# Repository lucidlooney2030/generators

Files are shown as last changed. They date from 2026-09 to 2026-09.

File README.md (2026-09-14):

# Generators

Printable desktop **magnetic generators** by [Austin Carolino](https://github.com/lucidlooney2030).

Educational Faraday machines: mechanical work in → electricity out. **Not** free-energy / overunity devices.

**System / voice-to-parametric process:** [idea-to-print-pipeline](https://github.com/lucidlooney2030/idea-to-print-pipeline)
This repo is the **hardware library** (OpenSCAD + STL + physics notes). New topology work still lands here. Pipeline work (agents, CadQuery port, gates) lands in the system repo.

| Project | Topology | Print first |
|---|---|---|
| [**HF-RF16-SERP**](HF-RF16-SERP/) | Radial-flux **outer rotor**, 16P/16S single-phase **wave** winding | [`stl/HF-RF16-ONEPLATE.stl`](HF-RF16-SERP/stl/HF-RF16-ONEPLATE.stl) |
| [**AFPM-Desk-v1**](AFPM-Desk-v1/) | Axial-flux, hand-crank, single rotor | `stl/` parts |
| [**AFPM-Desk-v2**](AFPM-Desk-v2/) | Axial-flux dual-rotor SSDR + steel back-iron | `stl/fit_coupon.stl` then parts |
| [**Coax-Faraday-v3**](Coax-Faraday-v3/) | Coaxial dual magnet drums + fixed coil | `stl/fit_coupon.stl` then parts |
| [**AFPM-Desk-v4 PoleShoe**](AFPM-Desk-v4-PoleShoe/) | Axial-flux dual-rotor + steel back-iron + pole shoes, 12+12 / 9-coil 3-phase | `stl/fit_coupon.stl` then parts |

## Printer

Anycubic **Kobra 3 Max** (or similar). Prefer **PETG / ABS / ASA / nylon**. HF-RF16: do **not** use PLA.

## Safety

Neodymium magnets pinch and shatter. Eye protection. Dual-magnet and outer-rotor builds have strong attractive forces — assemble with spacers.

## License

MIT — print, remix, share. Attribution appreciated.

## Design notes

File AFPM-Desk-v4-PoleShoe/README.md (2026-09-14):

# Generator Experiments v4 — AFPM-Desk-v4 PoleShoe

**Owner:** Austin Carolino  
**Build name:** AFPM-Desk-v4 PoleShoe  
**Purpose:** Desktop educational **SSDR dual-rotor axial-flux PM** generator with **mild-steel back-iron** plus **mild-steel pole shoes / flux concentrators** under each magnet.  
**Not a free-energy / overunity device.** Electrical energy out ≤ mechanical energy in (hand crank). Orthodoxy: Faraday induction + energy conservation only.

**Date package:** 2026-09-13 (America/New_York)  
**Evolves from:** v2 AFPM-Desk dual-rotor sandwich (`/workspace/generator-experiments/v2/`)

---

## What changed vs v2

| Feature | v2 | v4 (this package) |
|---|----|---|
| Topology | SSDR sandwich + steel back-iron | SSDR + **back-iron + pole shoes** |
| Magnets | 8+8 Ø20×**3** N42 | **12+12** Ø20×**5** N42 (Austin stock) |
| Flux teaching | Back-iron return path | Back-iron **+** Ø18×2 mm shoes under each magnet (reluctance / concentration) |
| Coils | 6 | **9** (true 3-phase Y or Δ) |
| Air gap | ~2 mm/side | **1.5–2.0 mm**/side (parametric spacers) |
| Material | PLA/PETG | **PETG** preferred (Kobra 3 Max) |
| Poles | P=8 → f=4·RPM/60 | **P=12 → f=6·RPM/60** |

---

## Package contents

| Path | Description |
|---|---|
| `README.md` | This overview |
| `BUILD.md` | Assembly steps + safety |
| `PARTS.md` | Labeled part list + debrief |
| `SCHEMATIC.md` | Polarity, wiring, mechanical stack |
| `PHYSICS.md` | Faraday estimates, citations, Voc OOM |
| `PRINT_NOTES.md` | Orientation, supports, PETG settings |
| `FIT_COUPON.md` | Print-first clearance coupon |
| `MANIFEST.md` | File inventory |
| `scad/*.scad` | Parametric OpenSCAD |
| `stl/*.stl` | Binary STLs |
| `sim/` | Numpy Voc vs RPM sanity check |

---

## Topology (why 12/9)

Classic low-speed AFPM educational choice (Latoufis et al. rural AFPM lineage):

1. **12 poles / 9 coils** → natural 3-phase with 120° electrical spacing of coil groups.
2. Thicker Ø20×5 magnets raise source MMF vs v2’s Ø20×3.
3. **Pole shoes** (mild steel, slightly smaller than magnet face) teach flux concentration and reluctance — shoes sit under each magnet, ahead of the full back-iron disc.
4. Coreless plastic stator keeps cogging hand-crankable (still strong dual-N42 attraction — **pinch hazard**).

---

## Quick start

1. Print **`stl/fit_coupon.stl` first** → measure → tweak `scad/parameters.scad` → re-export if needed.
2. Read **PHYSICS.md** + **PARTS.md** (neo pinch / eyes / steel tools).
3. Print remaining STLs (**PETG**, 0.2 mm layers, 5 perimeters / 40% infill / 100% around pockets).
4. Buy BOM: 24× N42 Ø20×5, 24× mild-steel Ø18×2 pole shoes, 2× mild-steel Ø118×1.5 back-iron discs, 28 AWG, 2× 608ZZ, Ø8 shaft ~250 mm.
5. Assemble per **BUILD.md**; set **~1.5–2.0 mm** air gap each side with spacer rings.
6. Measure Voc @ 60–180 RPM; compare to PHYSICS / `sim/`.

---

## Desk-scale electrical targets (order of magnitude)

- Hand crank **60–120 RPM** → roughly **~1–8 Vrms** open-circuit depending on series / Y wiring (see PHYSICS.md).
- @ **120 RPM** conservative model: ~**0.8–1.2 Vrms / coil**, ~**2.5–4 Vrms / phase** (3 coils series), LED-scale after Schottky bridge.
- Educational power: **order of watts**, not utility / battery-bank without further engineering.

---

## Physics stance (explicit)

Converts **mechanical → electrical**. Friction, I²R, eddy/hysteresis in steel, and magnetic drag ⇒ η < 1.  
**No perpetual motion, free energy, or overunity claims.** Pole shoes and thicker magnets improve **coupling** of the work you put in.

---

## Printer assumptions

Anycubic **Kobra 3 Max**, **0.4 mm nozzle**, **0.2 mm layers**, **PETG**.  
Skill: `/home/box/agent-data/workflows/kobra-stl-from-description/SKILL.md`.

Local root: `/workspace/generator-experiments/v4/`

---
*Generator Experiments · Magneat-o cycle · v4 PoleShoe*

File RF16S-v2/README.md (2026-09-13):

# RF16S-v2 — dual-rotor radial flux (CURRENT)

**This is newer than everything else in this repo from 2026-09-13.**

Do not print AFPM-Desk-v1, AFPM-Desk-v2, HF-RF16, or HF-RF88 for this build. Those are earlier machines. This folder is the water-turbine radial generator:

- 16 × Ø20×5 mm discs on the **outer** cup, facing in
- 48 × Ø5×5 mm N52 cylinders on the **inner** hub (16 poles × 3 stacked), facing out
- 16-window coil cage between them
- Matched 16/16 poles, 22.5° pitch, 1.00 mm air gap both sides

## Print these four STLs

| File | What it is |
|---|---|
| `stl/HF-RF16S-v2-OUTER.stl` | Outer cup |
| `stl/HF-RF16S-v2-INNER.stl` | Inner hub (rim + spokes, not a solid puck) |
| `stl/HF-RF16S-v2-CAGE.stl` | Coil cage |
| `stl/HF-RF16S-v2-CAP.stl` | End cap |

Direct downloads (once the STLs are in this folder):
- https://github.com/lucidlooney2030/generators/raw/main/RF16S-v2/stl/HF-RF16S-v2-OUTER.stl
- https://github.com/lucidlooney2030/generators/raw/main/RF16S-v2/stl/HF-RF16S-v2-INNER.stl
- https://github.com/lucidlooney2030/generators/raw/main/RF16S-v2/stl/HF-RF16S-v2-CAGE.stl
- https://github.com/lucidlooney2030/generators/raw/main/RF16S-v2/stl/HF-RF16S-v2-CAP.stl

## Anycubic / Orca

- PETG. Not PLA.
- **Supports = Off**
- Slicer brim = Off (a 0.6 mm brim is already on the part)
- Layer 0.20 mm, first layer 0.24 mm
- 4 walls, 20% gyroid
- Outer walls first
- First layer 20 mm/s, bed ~75 °C, nozzle ~240 °C
- Pockets and cage windows face **up**
- Peel the brim when cold

## Magnets

Outer: N-S-N-S around the circle.
Inner: each column of 3 small magnets is one pole, all three the same way, **opposite** the outer magnet it faces (they attract across a window).

Steel strip 1.5 × 20 mm behind **both** rings.

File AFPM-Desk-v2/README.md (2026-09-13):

# Generator Experiments v2 — AFPM-Desk Dual-Rotor Sandwich

**Owner:** Austin Carolino  
**Build name:** AFPM-Desk-v2  
**Purpose:** Desktop educational **dual-rotor axial-flux permanent-magnet (AFPM)** generator with **steel back-iron**.  
**Not a free-energy / overunity device.** Electrical energy out ≤ mechanical energy in (hand crank). Orthodoxy: Maxwell–Faraday induction + energy conservation only.

**Date package:** 2026-09-10 (America/New_York)  
**Evolves from:** v1 AFPM-Desk (single rotor, 8× N42, 6 coils) — Drive folder [v1](https://drive.google.com/drive/folders/12ztOcHBTHuGbHydsOmjWQckuVxojFjWz)

---

## What changed vs v1

| Feature | v1 | v2 (this package) |
|---|----|---|
| Topology | Single rotor / single stator | **SSDR sandwich**: dual rotors + stator between |
| Magnets | 8× N42 Ø20×3 | **8+8** (16×) N42 Ø20×3 facing across stator |
| Back-iron | None (plastic return) | **Mild steel discs** Ø100×1.5 mm behind each magnet set |
| Coils | 6 | **6** (continuity; 3-phase capable) |
| Expected B_g | ~0.25–0.40 T | ~**0.40–0.60 T** (order-of-magnitude) |
| Air gap | 2–3 mm one side | **1.5–2.5 mm each side** magnet↔coil |
| Learning goal | Basic Faraday demo | Higher flux, feel stronger cogging, compare single vs dual |

---

## Package contents

| Path | Description |
|---|---|
| `README.md` | This overview |
| `BUILD.md` | Assembly steps + print notes |
| `PARTS.md` | Labeled part list, BOM, physics debrief per part |
| `SCHEMATIC.md` | Polarity, wiring, mechanical stack |
| `PHYSICS.md` | Faraday estimates, citations, sanity checks |
| `FIT_COUPON.md` | Print-first clearance coupon procedure |
| `PRINT_NOTES.md` | Orientation, supports, pause-for-magnets |
| `scad/*.scad` | Parametric OpenSCAD sources |
| `stl/*.stl` | Binary STLs for Anycubic Kobra 3 Max |

---

## Topology choice (documented)

**8+8 magnets / 6 coils** kept deliberately:

1. **Continuity with v1** — reuse coil winding skill and 8-magnet pattern; buy 8 more discs.
2. **Educational clarity** — alternating N/S on each rotor; facing magnets **attract** (N faces S across gap) so flux threads the coils axially.
3. **3-phase option** — wire coils as A=(C0+C3), B=(C1+C4), C=(C2+C5) like v1.
4. **Why not 12/9 yet?** Commercial DIY AFPM often uses 12 poles / 9 coils for smoother 3-phase at wind-turbine scale (Latoufis et al.). For desk hand-crank learning, 8/6 is adequate and simpler. A v3 could migrate to 12+12/9 if wanted.

**Steel back-iron role:** provides a low-reluctance return path between adjacent poles on each rotor, raising air-gap flux density versus the plastic-only v1 disc, and reducing stray flux behind the magnets (Gieras / AFPM literature; Latoufis rural-electrification AFPM notes).

**Coreless stator:** plastic plate + copper coils only — **no iron teeth** → low cogging for hand crank (still some detent from magnet–magnet attraction across the gap). Tradeoff: thicker magnetic gap than slotted iron stator → B_g lower than industrial iron-cored AFPM, but safer and smoother for learning.

---

## Quick start

1. Print **`fit_coupon.stl` first** → measure → tweak `scad/parameters.scad` if needed → re-export.
2. Read **PHYSICS.md** + **PARTS.md** (safety: neo pinch / eyes).
3. Print remaining STLs (PLA or PETG, 0.2 mm layers, ≥3–4 perimeters on rotors/frame).
4. Buy BOM (16× N42, 2× steel discs, 28 AWG, 608 bearings, Ø8 shaft ~220 mm).
5. Assemble per **BUILD.md**; set **~2 mm air gap each side**.
6. Measure open-circuit AC @ ~60–120 RPM; compare to PHYSICS estimates.

---

## Desk-scale electrical targets (order of magnitude)

- Hand crank **60–120 RPM** → roughly **~1–8 Vrms** open-circuit depending on series/3-phase wiring (see PHYSICS.md).
- Peak educational power: **order of watts** (LED / small loads), **not** mains / battery-bank charging without further engineering.
- Voltage stays **low-energy educational** at hand speed — still use eye protection for magnets.

---

## Physics stance (explicit)

Converts **mechanical → electrical**. Friction, I²R, and magnetic drag ⇒ η < 1. **No perpetual motion, free energy, or overunity claims.** Dual rotors and steel raise coupling; they do not create energy.

---

## Printer assumptions

Anycubic **Kobra 3 Max**, **0.4 mm nozzle**, **0.2 mm layers**, **PLA or PETG**. Skill: `/home/box/agent-data/workflows/kobra-stl-from-description/SKILL.md`.

---

## Upload note

Large binary STLs often cannot upload intact via the Google Drive connector. Docs (markdown) upload fine; place STLs in Drive **Generator Experiments / v2** manually from this package if needed.

Local root: `/workspace/generator-experiments/v2/`

---
*Generator Experiments · Magneat-o cycle · v2*

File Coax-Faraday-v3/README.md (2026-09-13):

# Generator Experiments v3 — Coaxial Faraday Desk Generator

**Austin Carolino** · educational Faraday machine · orthodox physics only  
**Not** free energy / overunity / perpetual motion.

## What it is
A **simple three-layer coaxial** hand-crank generator for Anycubic **Kobra 3 Max** (PETG, 0.4 mm nozzle, 0.2 mm layers):

1. **Outer** magnet drum — Ø20×5 mm N42 discs, faces **inward**
2. **Middle** fixed copper coil stator (bobbin)
3. **Inner** magnet drum — Ø20×5 mm N42 discs, faces **outward**

**Topology:** outer + inner drums are **mechanically locked** and rotate together as one rotor; the coil cylinder is the **stationary stator**. No brushes. Flux crosses the coil **radially**.

## Why this topology
- Stationary coils → no brushes, desk-safe low voltage
- Dual facing magnets raise gap flux vs single-sided
- Matched pole count (P=8) with alternating N/S around the circumference

## Magnet decision
**Assumption:** “20×5 mm” = **Ø20×5 mm discs** (not bar stock) — common catalog size (e.g. supermagnete S-20-05-N N42).

**Inner choice: Ø20×5 discs (not Ø3×5 cans).**  
Simulation FoM \(P\cdot\Phi\): Ø20 dual ≫ Ø3 dual (area ratio \((3/20)^2\approx2.25\%\)). Outer Ø20 already limits pole count, so tiny inner magnets buy no useful frequency and lose flux.

## Expected order of magnitude (@ 120 RPM, baseline)
From `sim/` (N42, P=8, 2 mm gaps, 26 AWG, dual Ø20):

| Quantity | Estimate |
|---|---|
| \(f\) | 8 Hz |
| Voc rms | **~4 V** |
| Voc peak | **~6 V** |
| LED current (100 Ω + 2 V LED, naive bridge) | **~17 mA** |

Hand-crank 60–300 RPM → LED demo territory; not a power plant.

## Package layout
```
v3/
  README.md  PHYSICS.md  DEBRIEF.md  SCHEMATIC.md  PRINT_NOTES.md
  scad/   parametric OpenSCAD
  stl/    binary STLs
  sim/    numpy sweep + CSV + plots
  scripts/export_stls.sh
```

## Quick start
1. Print `fit_coupon.stl` in PETG; dial magnet/bearing fits.
2. Print drums, stator halves, base, hubs, crank.
3. Epoxy magnets with **polarity_jig** (alternating).
4. Wind stator (26–28 AWG), assemble, crank into an LED + series resistor.

See **DEBRIEF.md** for BOM/assembly and **PHYSICS.md** for equations & safety.

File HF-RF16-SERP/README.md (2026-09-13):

# HF-RF16-SERP  16P/16S

**Radial-flux OUTER-ROTOR generator · single-phase wave (serpentine) winding**  
For **Austin Carolino** · units **mm** · FROM SCRATCH (not axial flux, no pancake coils, no 9-bobbin concentrated winding, no magnet platter).

| | |
|---|---|
| Topology | Rotor cup spins **around** stationary stator drum |
| Poles / slots | **16** disc magnets / **16** axial grooves |
| Winding | One continuous serpentine/wave, 26 AWG, target 80–120 turns |
| Air gap | **1.00 mm** (locked; do not exceed 1.2) |

---

## Geometry conflict resolution

**Problem.** Early notes mixed a drum bore of 47.00 with groove floor **r = 47.38**, leaving only **0.38 mm** of printed wall (below the ≥2.00 mm minimum). Sleeve outer was corrected to **r = 55.38** (wall 0.80), and a copper fill of “~7.2” no longer matched.

**Chosen resolution (preferred):**

| Stack item | Value |
|---|---|
| Magnet inner-face pitch radius | **56.38** |
| Air gap | **1.00** |
| Sleeve OUTER / INNER r | **55.38** / **54.58** (wall 0.80) |
| Printed bore **radius** | **47.00** → bore **Ø94.00** |
| Groove floor r | **49.00** (not 47.38) |
| Printed wall (bore → floor) | **2.00** |
| Copper radial fill | 55.38 − 0.80 − 49.00 = **5.58** (revises “7.2”) |
| Groove open (pre-sleeve) | r = **55.38** |
| Land / groove arcs @ 55.38 | **9.75** / **12.00** (sum 21.75 = pitch arc; **no ±0.5 tweak**) |

**Steel tube:** Legacy BOM “OD~47” matched the **bore radius** figure. Corrected bought tube: **OD ≈ 94 mm**, wall ~3 mm, length ~28 mm — slip fit in Ø94 bore.

Angular pitch remains **16 × 22.50°**.

---

## Key dimensions

| Parameter | mm |
|---|---|
| Magnets | 16× Ø20.00×5.00 NdFeB, faces inward, N-S-N-S |
| Magnet backs | r = 61.38 |
| Rotor OD | 132.00 |
| Back-iron groove | r = 61.38–62.88 × axial 20.20; strip cut **386** |
| Stator axial (groove+galleries) | 32.00 |
| Pocket Ø / depth / lip ID | 20.30 / 5.20 / 18.40 (lip thk 0.80) |
| 608ZZ seats | Ø22.20 × 7.20 deep (×2: rotor + cap) |

---

## Deliverables

| File | Description |
|---|---|
| `hf_rf16_params.py` | Locked parameters (`MAG_COUNT=16`) |
| `hf_rf16_cad.py` | Parametric CadQuery → STEP + STL |
| `hf_rf16_drawing.py` | Drawing generator |
| `HF-RF16-ROTOR.stl` / `.step` | Outer rotor cup |
| `HF-RF16-STATOR.stl` / `.step` | Grooved stator drum |
| `HF-RF16-SLEEVE.stl` / `.step` | Two 180° post-wind shells |
| `HF-RF16-CAP.stl` / `.step` | End cap + 2nd bearing |
| `HF-RF16-ASSEMBLY.step` | Positioned assembly |
| `HF-RF16-ONEPLATE.stl` | All parts, 8 mm gaps (300 mm bed) |
| `HF-RF16-DRAWING.pdf` (+ png/svg) | Dimensioned drawing set |
| `PHYSICS_NOTE.md` | Faraday sanity |
| `PRINT_NOTES.md` | Print orientation & settings |
| `BOM.md` | Bought + printed BOM |

Rebuild:

```bash
cd /workspace/generator-experiments/HF-RF16
.venv/bin/python hf_rf16_cad.py
.venv/bin/python hf_rf16_drawing.py
```

---

## Build overview

Print rotor (pockets up), stator (grooves up), sleeve halves (flat), and cap (flat) in PETG/ABS/ASA/nylon — never PLA. Press 16× Ø20×5 NdFeB into rotor pockets alternating N-S (centrifugal seats outboard; lip retains inward). Slide 1.5×20 mild-steel strip (cut 386) into the back-iron groove. Fit steel tube Ø94 into stator bore. Wave-wind 26 AWG through all 16 grooves with end-turn galleries (up 1, over, down 2, …), use the return slot for multi-turn, exit tails through cap grommets. Clip on sleeve halves after winding. Assemble on Ø8 shaft with two 608ZZ (rotor cup rotates; stator fixed via cap). Rectify with a 4-diode bridge and ≥1000 µF.

**Constraints honored:** radial flux only · magnets on inner wall of rotating cup · coil active length axial · serpentine pitch = pole pitch · no stator teeth · air gap 1.00.

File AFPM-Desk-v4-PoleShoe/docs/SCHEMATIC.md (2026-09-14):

# SCHEMATIC — AFPM-Desk-v4 PoleShoe

## 1. Mechanical stack (axial, along shaft)

```
[crank][608ZZ][hub][rotorA+shoes+magnets][steel A]
        |← ~1.5–2.0 mm air →|
      [stator + 9 coils]
        |← ~1.5–2.0 mm air →|
[steel B][rotorB+shoes+magnets][hub][608ZZ]
```

Nominal air gap each side: magnet face ↔ coil/bobbin face. Tune with `spacer_1mm` / `1p5mm` / `2mm`.

---

## 2. Rotor polarity (P=12)

Looking along shaft toward rotor A stator face. Stations every 30°.

| Station index | Angle | Rotor A face (→ stator) | Rotor B face (→ stator) |
|---|---|---|---|
| 0 | 0° | **N** | **S** |
| 1 | 30° | **S** | **N** |
| 2 | 60° | **N** | **S** |
| … | … | alternate | opposite of A |

Facing pair at each station: **N faces S** so axial flux threads the coils. Adjacent magnets on one rotor alternate → circumferential return via back-iron.

Pole shoe under every magnet (both rotors).

Printed etch: bar = N, cross = S (rotor A pattern on jig; rotor B opposite).

---

## 3. Coil map (9 coils)

Coils seated at angles \(20° + i·40°\) (i = 0…8) so pockets sit between/aligned for 12-pole AFPM coupling.

**3-phase grouping (120° electrical):**

| Phase | Coil indices | Mechanical spacing |
|---|---|---|
| **A** | 0, 3, 6 | every 3rd coil |
| **B** | 1, 4, 7 | |
| **C** | 2, 5, 8 | |

Within a phase, series-connect with **aiding** sense (same wind direction relative to flux). If Voc collapses, reverse one coil in the group.

### Star (Y)

```
Phase A ────●
Phase B ────●─── neutral (optional bring-out)
Phase C ────●
```

Line-line Voc ≈ √3 × phase Voc (balanced OC idealization).

### Delta (Δ)

```
A ──●── B
 \     /
  ●───●
    C
```

Higher current capability, lower line V — useful for low-V LED experiments.

---

## 4. LED demo (desk-safe)

```
[Y or Δ phases] → Schottky bridge → C filter (optional 100–470 µF) → Rseries (100–220 Ω) → LED
```

Si bridge (~1.4 V drop) eats much of the LED budget; **Schottky** preferred.

---

## 5. Frequency check

\[
f = \frac{\mathrm{RPM}}{60}\cdot\frac{P}{2} = 6\cdot\frac{\mathrm{RPM}}{60}
\]

| RPM | f (Hz) |
|-----|---|
| 60 | 6 |
| 120 | 12 |
| 180 | 18 |

Scope one coil: period should match. Wrong f → wrong pole count / mechanical slip (should be locked).

---

## 6. What not to wire

- Do **not** connect to mains.
- Do **not** short all coils while spinning at high RPM (heating + strong drag).
- Do **not** claim self-running / overunity — Lenz drag always costs mechanical power.

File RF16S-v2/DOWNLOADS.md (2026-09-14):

# Downloads

STLs are not in git yet. Rebuild from the pipeline family, or attach the local meshes named:

- radial_flux_16_inward_rotor.stl
- 03_serpentine_coil_former(1).stl
- 02_inner_magnet_hub.stl

System repo: https://github.com/lucidlooney2030/idea-to-print-pipeline/tree/main/families/radial_outer

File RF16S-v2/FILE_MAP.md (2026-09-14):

# Name map (your files → this folder)

| Your filename | This project |
|---|---|
| `radial_flux_16_inward_rotor.stl` | outer cup → `stl/HF-RF16S-v2-OUTER.stl` |
| `03_serpentine_coil_former(1).stl` | coil cage → `stl/HF-RF16S-v2-CAGE.stl` |
| `02_inner_magnet_hub.stl` | inner hub → `stl/HF-RF16S-v2-INNER.stl` |

Parametric source of truth for the rebuild:  
https://github.com/lucidlooney2030/idea-to-print-pipeline/tree/main/families/radial_outer

Those three exact names were not in this repo when checked. If you still have the meshes, put them in `RF16S-v2/reference/` so we can compare bbox vs the CadQuery rebuild. Do not hand-edit them.

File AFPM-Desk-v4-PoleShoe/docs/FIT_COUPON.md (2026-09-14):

# FIT_COUPON — print first

File: `stl/fit_coupon.stl` (95×55×8 mm)

## What it tests

1. **Shaft hole ladder** — Ø8.2, 8.3, 8.4, 8.5 (pick slip fit for Ø8 shaft).
2. **608ZZ seats** — OD −0.20 / −0.15 / −0.10 mm (pick firm press).
3. **Magnet pocket** — Ø20.25 × depth ~5.15 for Ø20×5 disc.
4. **Pole-shoe pocket** — Ø18.30 × depth ~2.15 for Ø18×2 steel.
5. **M3 clear (3.4) / tap pilot (2.5)**.

## Procedure

1. Print in **PETG**, same settings as final parts.
2. Calipers: record actual hole IDs and pocket depths.
3. Edit `scad/parameters.scad`:
   - `clearance_slip`, `press_interference`
   - `magnet_pocket_xy`, `magnet_pocket_z`
   - `pole_shoe_pocket_xy`, `pole_shoe_pocket_z`
4. Re-export affected STLs with OpenSCAD before printing rotors/frame.

Do **not** skip this — dual neo arrays punish bad fits.

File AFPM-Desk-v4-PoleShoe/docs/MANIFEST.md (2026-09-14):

# MANIFEST — AFPM-Desk-v4 PoleShoe

Package root: `/workspace/generator-experiments/v4/`  
Archive: `/workspace/afpm_desk_v4_full_package.tar.gz`

## Documentation

- README.md
- BUILD.md
- PARTS.md
- SCHEMATIC.md
- PHYSICS.md
- PRINT_NOTES.md
- FIT_COUPON.md
- MANIFEST.md (this file)

## OpenSCAD (`scad/`)

- parameters.scad
- rotor_disc.scad, rotor_disc_A.scad, rotor_disc_B.scad
- stator_plate.scad, coil_bobbin.scad
- base_frame.scad, shaft_hub.scad, bearing_cap.scad
- hand_crank.scad, crank_handle.scad
- spacer_ring.scad, spacer_1mm.scad, spacer_1p5mm.scad, spacer_2mm.scad
- fit_coupon.scad, polarity_jig.scad, pole_shoe_holder.scad
- electronics_tray.scad

## Binary STLs (`stl/`)

- base_frame.stl
- rotor_disc_A.stl, rotor_disc_B.stl
- stator_plate.stl, coil_bobbin.stl
- shaft_hub.stl, bearing_cap.stl
- hand_crank.stl, crank_handle.stl
- spacer_1mm.stl, spacer_1p5mm.stl, spacer_2mm.stl
- fit_coupon.stl, polarity_jig.stl, pole_shoe_holder.stl
- electronics_tray.stl

## Simulation (`sim/`)

- afpm_desk_v4.py
- sweep_results.csv
- sim_summary.txt
- voc_vs_rpm.png, voc_vs_gap.png

## Regenerating STLs

```bash
cd /workspace/generator-experiments/v4
for p in scad/*.scad; do
  b=$(basename "$p" .scad)
  case "$b" in parameters|rotor_disc|spacer_ring) continue;; esac
  openscad -o "stl/${b}.stl" "$p"
done
# then convert ASCII→binary if needed via trimesh / stl2bin
```

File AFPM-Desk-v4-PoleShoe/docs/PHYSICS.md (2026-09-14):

# PHYSICS — AFPM-Desk-v4 PoleShoe

Educational estimates. **Reject perpetual motion / overunity / “magnets alone make free power.”**  
Mechanical work against Lenz drag → electrical energy (+ heat).

Assumptions stated. **No fabricated lab measurements** — order-of-magnitude from standard EM relations + cited material properties. Validate with a DMM/tach on your build.

---

## 1. Governing equations

\[
\mathcal{E} = -N\frac{d\Phi_B}{dt}
\]

For approximately sinusoidal flux through one coil:

\[
\Phi(t)\approx\Phi_{\mathrm{peak}}\sin(2\pi f t)
\quad\Rightarrow\quad
\mathcal{E}_{\mathrm{peak}}\approx N\cdot 2\pi f\cdot\Phi_{\mathrm{peak}}
\]

\[
\mathcal{E}_{\mathrm{rms}}\approx\mathcal{E}_{\mathrm{peak}}/\sqrt{2}
\]

Electrical frequency for \(P\) poles:

\[
f=\frac{\mathrm{RPM}}{60}\cdot\frac{P}{2}
\]

**v4:** \(P=12\) → \(f=6\times(\mathrm{RPM}/60)\).

| RPM | \(f\) (Hz) |
|-----|---|
| 60  | 6 |
| 90  | 9 |
| 120 | **12** |
| 180 | 18 |

(Refs: synchronous-machine frequency relation; AFPM modelling e.g. Gieras; [MDPI Energies 13(21):5741](https://www.mdpi.com/1996-1073/13/21/5741).)

---

## 2. Magnet material

**Assumption:** Ø20×5 mm axial N42 discs (Austin stock).

| Grade | Br (typical) | Sources |
|---|---|---|
| **N42** | **1.28–1.32 T** (use **1.30 T**) | [supermagnete S-20-05-N](https://www.supermagnete.nl/eng/data_sheet_S-20-05-N.pdf); manufacturer N42 bands |

Gap flux **≠ Br**. Remanence is a material property; useful \(B_g\) depends on reluctance of air + coil path + leakage + steel return.

---

## 3. Topology & flux path

```
[steel back-iron A][pole shoe][magnet A Ø20×5]
        -- air gap (~1.75 mm) --
              [coil / plastic]
        -- air gap (~1.75 mm) --
[magnet B Ø20×5][pole shoe][steel back-iron B]
```

- Facing magnets **N↔S** across stator → axial flux through coils.
- Adjacent magnets on one rotor **alternate** N/S.
- **Back-iron:** low-reluctance circumferential return (classic SSDR AFPM).
- **Pole shoes (Ø18×2 mild steel under each magnet):** locally lower reluctance and teach **flux concentration / reluctance** — shoes do not create energy; they reshape the magnetic circuit.

Coreless stator (no iron teeth): smoother hand crank, thicker effective magnetic gap than slotted industrial AFPM.

---

## 4. Air-gap flux density model (assumptions)

Non-steel path (order of magnitude):

| Segment | Thickness |
|---|---|
| Magnet A | 5 mm |
| Mechanical air A | ~1.5–2.0 mm (use 1.75) |
| Coil / plastic stator | ~10 mm effective |
| Mechanical air B | ~1.75 mm |
| Magnet B | 5 mm |

Crude series-reluctance estimate (µ_gap ~ 1):

\[
B_g \approx B_r\cdot\frac{L_{m,\mathrm{eff}}}{L_{m,\mathrm{eff}}+g_{\mathrm{eff}}}\cdot k_{\mathrm{leak}}
\]

with \(L_{m,\mathrm{eff}}\approx 2\times 5\,\mathrm{mm}\), \(g_{\mathrm{eff}}\approx 2\cdot\mathrm{gap}+\mathrm{coil\_axial}\), and \(k_{\mathrm{leak}}\approx 0.65\) (dual + steel + shoes; conservative).

| Case | \(B_g\) (model) |
|---|---|
| v2-like (3 mm mags, steel, no shoes) | ~0.23 T (same formula) |
| v4 no shoes (5 mm + steel) | ~0.32 T |
| **v4 + pole shoes (baseline)** | **~0.36 T** |
| Upper teaching band (less leakage) | ~0.45–0.55 T |

**Central conservative estimate used below: \(B_g = 0.36\,\mathrm{T}\).**  
Upper band ~0.50 T if shoes + steel couple better than the crude leak factor — treat as a sensitivity case, not a measured value.

Magnet face area:

\[
A_m=\pi(0.010)^2=3.14\times10^{-4}\,\mathrm{m}^2
\]

Coupling coil vs magnet footprint \(k_c\approx 0.70\) (9 coils / 12 poles fractional alignment):

\[
\Phi_{\mathrm{peak}}\approx k_c B_g A_m
\approx 0.70\times 0.36\times 3.14\times10^{-4}
\approx 7.9\times10^{-5}\,\mathrm{Wb}
\]

(Upper band Φ ≈ \(1.1\times10^{-4}\) Wb at \(B_g=0.50\,\mathrm{T}\).)

**vs v2:** thicker magnets + higher pole count + shoes raise \(f\) and improve Φ relative to a like-for-like reluctance model; absolute Voc also depends on turns and wiring.

---

## 5. Turns & resistance (LED demo recommendation)

| Item | Recommendation |
|---|---|
| Wire | **28 AWG** enamel Cu (~0.32 mm bare; ~0.213 Ω/m @ 20 °C typical) |
| Turns / coil | **~200** hand-wind target (bobbin window allows more if filled carefully) |
| Mean turn length | ≈ 0.08 m (24×16 mm core rectangle) |
| \(R_{\mathrm{coil}}\) | ≈ **3.4 Ω** @ 200 turns |

Alt: **26 AWG**, ~150 turns → lower R, easier LED current, slightly lower Voc.

---

## 6. Open-circuit voltage estimates

### One coil @ 120 RPM (\(f=12\,\mathrm{Hz}\), \(N=200\), Φ = 7.9×10⁻⁵ Wb)

\[
\mathcal{E}_{\mathrm{peak,1}}\approx 200\cdot 2\pi\cdot 12\cdot 7.9\times10^{-5}\approx 1.19\,\mathrm{V}
\]

\[
\mathcal{E}_{\mathrm{rms,1}}\approx 0.84\,\mathrm{V}
\]

Upper band (\(B_g=0.50\,\mathrm{T}\)): ~**1.1–1.2 Vrms** / coil.

### Scale with RPM (∝ f ∝ RPM)

| RPM | \(f\) | Voc rms / coil (cons.) |
|-----|---|---|
| 60 | 6 | ~0.42 V |
| 120 | 12 | ~**0.84 V** |
| 180 | 18 | ~1.3 V |

### Wiring aggregates @ 120 RPM (rough)

| Config | Expectation OC |
|---|---|
| Single coil | ~0.8–1.2 Vrms |
| 1 phase = 3 coils series | ~**2.5–3.5 Vrms** |
| Y line-line | ~**4–6 Vrms** (√3 × phase, ideal) |
| All series (careful aiding) | higher, phase-risk if wrong |

**Hand-crank band (60–180 RPM):** plan on **~1–8 Vrms** open-circuit depending on wiring — **LED-scale after rectification**, not utility voltage.

`sim/afpm_desk_v4.py` reproduces these curves (`voc_vs_rpm.png`, `sweep_results.csv`).

Diode bridge drop (~0.6–1.4 V) is significant at LED voltages — use Schottky.

---

## 7. Rough power

Example: rectified ~3 V into LED drawing 20–50 mA → \(P\sim 0.06\)–\(0.15\,\mathrm{W}\).  
Vigorous crank / smaller gap / denser winding → **~0.5–2 W** educational ballpark.

\[
P_{\mathrm{elec}} < P_{\mathrm{mech}}=\tau\omega
\]

Copper \(I^2R\), bearing friction, windage, and eddy/hysteresis in back-iron + pole shoes all reduce η. At hand RPM, steel eddy is modest if discs are thin (1.5–2 mm).

---

## 8. What pole shoes do *not* do

- Do **not** create energy from magnets alone.
- Do **not** enable self-running / overunity.
- Do **not** violate Faraday or Kelvin–Planck.
- They reshape reluctance so **more of your crank work** couples into \(d\Phi/dt\) (and a bit more steel loss).

---

## 9. Safety (magnetic)

- Dual **12+12 N42 Ø20×5** arrays: **severe pinch/crush**. Assemble with spacers; never put fingers in the gap.
- Non-magnetic tools; keep steel tools away from open faces.
- NdFeB shatter risk — eye protection; epoxy fully.
- Desk-safe low V electrically; still avoid hard shorts while cranking.

---

## 10. Citations & further reading

1. Faraday’s law — Griffiths *Introduction to Electrodynamics*; any intro EM text.
2. [Modeling of Axial Flux Permanent Magnet Generators](https://www.mdpi.com/1996-1073/13/21/5741) — Energies 13(21):5741 (2020).
3. Latoufis et al. — DIY AFPM sizing for small wind (12-pole / 9-coil practice).
4. Habib et al., SSDR coreless AFPM — *Alexandria Engineering Journal* (2024).
5. N42 NdFeB \(B_r\) — manufacturer datasheets (e.g. supermagnete S-20-05-N).
6. Reluctance / permeance methods — standard machine design texts (Gieras *Axial Flux Permanent Magnet Brushless Machines*).

Nuance: published AFPM papers often target kW machines; **scaling laws apply**, but absolute V/I here are desk-learning.

---

## 11. Measurement plan

1. Tach / phone RPM on rotor mark.
2. DMM ACV one coil vs RPM → slope ∝ \(N\Phi\).
3. Scope frequency → confirm \(f=6\cdot\mathrm{RPM}/60\).
4. Vary gap with spacer rings → Voc falls as gap rises.
5. Optional: compare Voc with vs without pole shoes (same magnets/gap) — expect modest rise with shoes if leakage was significant.

---
*End PHYSICS — AFPM-Desk-v4 PoleShoe*

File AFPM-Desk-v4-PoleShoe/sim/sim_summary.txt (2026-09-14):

AFPM-Desk-v4 PoleShoe sim summary
================================
Assumptions: N42 Br=1.3 T, P=12, gap=1.75 mm/side, coil axial=10 mm
Bg with pole shoes+back-iron (conservative): 0.360 T
Bg without shoes (steel only): 0.321 T
Bg v2-like (3 mm mag, no shoes): 0.232 T
Bg upper teaching band (shoes): 0.485 T
Phi_peak (conservative): 7.907e-05 Wb
Turns/coil (28 AWG hand target): 200, R≈3.4 Ω

@ 120 RPM: f=12.0 Hz
  Voc 1 coil rms (cons.): 0.843 V
  Voc 1 coil rms (upper): 1.138 V
  Voc phase (3 ser):      2.529 V
  Voc Y line-line:        4.381 V

Order-of-magnitude @ 120 RPM: ~0.8–3 Vrms / coil; ~2–8 Vrms / phase; LED-scale after rectification.
NOT free energy — mechanical work against Lenz drag supplies the power.

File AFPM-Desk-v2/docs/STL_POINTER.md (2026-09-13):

# STL / OpenSCAD package note — AFPM-Desk-v2

Large binary STL files often cannot upload intact through the Google Drive connector.

**Local package on Magneat-o computer:**
- Docs + STLs: `/workspace/generator-experiments/v2/`
- Archive: `/workspace/afpm_desk_v2_stls.tar.gz` (~1.8 MB of stl+scad+scripts)

**Please drop these into this Drive folder (`Generator Experiments / v2`) from the chat archive or Magneat-o desktop:**
- All files under `stl/*.stl` (17 binary STLs)
- Optionally `scad/*.scad` and `scripts/export_stls.sh`

Docs in this folder (README, BUILD, PARTS, SCHEMATIC, PHYSICS, PRINT_NOTES, FIT_COUPON, MANIFEST, DEBRIEF) are already uploaded as text.

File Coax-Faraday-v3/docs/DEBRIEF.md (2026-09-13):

# DEBRIEF — Coax Faraday v3

## Labeled parts (print)

| STL | Role | Qty |
|-----|---|-----|
| `fit_coupon.stl` | Magnet + 608 fit calibration | 1 |
| `outer_magnet_drum.stl` | Outer rotor cup, Ø20×5 pockets (N-in / S-in alt.) | 1 |
| `inner_magnet_drum.stl` | Inner rotor, Ø20×5 pockets (N-out / S-out alt.) | 1 |
| `stator_bobbin.stl` | Split coil former (both halves in one STL) | 1 file |
| `shaft_hub.stl` | Locks outer closed end + pilots inner to shaft | 1 |
| `rotor_end_cap.stl` | Open-end lock: outer drum ↔ shaft | 1 |
| `base.stl` | Floor + two 608 posts | 1 |
| `bearing_cap.stl` | Bearing retainers | 2 |
| `hand_crank.stl` + `crank_handle.stl` | Drive | 1+1 |
| `polarity_jig.stl` | Alternating N/S seating guide | 1 |
| `spacer_*.stl` | Axial shims 1 / 1.5 / 2 mm | as needed |

**Bought hardware**

| Item | Spec | Qty | ~USD |
|---|---|-----|---|
| NdFeB discs | Ø20×5 mm N42 (Ni) | 16 | 25–40 |
| 608-2RS bearings | 8×22×7 mm | 2 | 3–6 |
| Shaft | Ø8 mm steel rod ~150 mm | 1 | 3–5 |
| Magnet wire | 26 AWG (or 28) enamel Cu ~30–50 m | 1 | 8–12 |
| M3 screws/nuts | assorted 8–20 mm | ~20 | 3–5 |
| Epoxy | 5–min or slow clear | 1 | 5–8 |
| LED + 100 Ω | demo load | 1 set | 1 |
| Bridge rectifier | W04G or 4×1N4007 | 1 | 1–2 |
| **Total** | | | **~50–80 USD** |

Optional: multimeter, hand tach / phone RPM app, thin wood stick for magnet placement.

---

## Assembly (short)

1. **Fit coupon** — confirm magnet press/slip and 608 seat; adjust OpenSCAD `magnet_pocket_xy` / `press_interference` if needed; reprint drums only if off.
2. **Magnets** — using `polarity_jig`, mark alternating poles. Epoxy 8 into **inner** (faces out) and 8 into **outer** (faces in). Match angles so facing pairs are N-in/N-out (see SCHEMATIC). Cure fully.
3. **Wind stator** — clamp bobbin halves; wind 26 AWG into the radial window (aim fill ~50–60%). Bring out leads through exit slot. Tape/varnish. Mount feet to base.
4. **Rotor** — press bearings into base posts; shaft through. Mount `shaft_hub` + outer drum closed end + inner drum on shaft so magnets align axially with coil. Fit `rotor_end_cap`. Verify **~2 mm** radial air gap each side (no rub).
5. **Crank** — attach hand crank; spin free (expect cogging).
6. **Electrical** — coil → bridge → 100 Ω → LED (or Voc on DMM AC/DC as wired).

---

## What to measure

| Test | Method | Expect (order) |
|---|---|---|
| Voc vs RPM | DMM + tach at 60/120/300 RPM | ~2 / ~4 / ~10 Vrms (baseline model) |
| Loaded LED | series 100 Ω | glow by ~100–150 RPM |
| Gap sensitivity | spacer / reprint | Voc falls as gap ↑ |
| Cogging | feel / stall torque | stronger with dual magnets |
| R_coil | DMM | tens of ohms (sim ~50 Ω @ 26 AWG) |

Compare to `sim/voc_vs_rpm.png`. Large misses → check polarity map, turns count, rubs, or gap.

---

## Optimum simple build (picked)

- Dual Ø20×5, P=8, 2 mm gaps, 26 AWG, locked dual-rotor / fixed stator  
- Skip Ø3 cans, skip 3-phase for v3 (single-phase series is enough for LED lab)

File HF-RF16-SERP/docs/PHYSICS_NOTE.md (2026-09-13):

# PHYSICS_NOTE — HF-RF16-SERP 16P/16S

Orthodox Faraday estimate only. No exotic claims.

## Machine class

- **Radial flux**, **outer rotor**: magnets on the **inner** cylindrical wall of a rotating cup.
- Flux crosses the **1.00 mm** air gap **radially** into the stator.
- Coil **active length is axial** (20 mm groove span), not circumferential pancakes.
- **16 poles / 16 slots**, single-phase **serpentine (wave)** winding with pitch = pole pitch = **22.5°**.
- Stator has **open grooves / lands (no ferromagnetic teeth)**; mild-steel tube provides flux return at the bore.

## Why EMF appears

Each magnet pole sweeps past an axial conductor once per pole pitch. For a single axial run of length ℓ in a radial field B_r at radius R, the motional EMF is on the order of:

\[
e \sim B_r\,\ell\,v = B_r\,\ell\,(\omega R)
\]

With N_turns series wave turns (each turn ≈ two axial runs for a full go-and-return across the machine, depending on count), AC EMF scales as:

\[
E_{\mathrm{rms}} \sim k\,N\,B_r\,\ell\,R\,\omega
\]

Electrical frequency: \(f_e = N_p\,n_{\mathrm{rev}}\) with \(N_p = 8\) pole-**pairs** (16 poles) → \(f_e = 8\,n\) (rev/s).

## Order-of-magnitude (sanity, not a promise)

Assume:

| Symbol | Rough value |
|---|---|
| B_r in gap | 0.3–0.6 T (NdFeB Ø20×5 behind ~1 mm gap + sleeve; no iron teeth → toward low end) |
| ℓ active | ~0.020 m |
| R | ~0.056 m |
| N | 80–120 turns |
| ω | 157 rad/s (≈1500 rpm) |

Then per-turn peak ~ BℓωR ≈ 0.4×0.02×157×0.056 ≈ **0.07 V**, ×100 turns × coupling factor ~0.3–0.6 (single-phase serpentine, leakage without teeth) → **low single-digit to low tens of volts** open-circuit at that speed. Power is modest; this is a learning / light-duty PMG, not a multi-kW machine.

Rectify with a full-wave bridge and bulk capacitor (≥1000 µF) for DC experiments.

## Design implications called out

1. **No stator teeth** → higher reluctance / leakage than a slotted iron stator; B_r and coupling are deliberately conservative above.
2. **Steel tube at bore r≈47** is the main flux return; lands are printed polymer.
3. **Outer rotor** keeps magnet mass at larger radius (good for inertia / turbine coupling) with centrifugal seating into pocket floors.
4. Serpentine single-phase → pulsating torque / ripple; expect vibration vs. a three-phase machine.

All estimates are classical Faraday / Lorentz; validate on the bench with a known rpm and scope.

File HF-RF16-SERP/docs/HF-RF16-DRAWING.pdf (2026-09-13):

### Axial cross-section (radial stack-up)

### Rotor polar layout — 16×22.5° magnet pockets

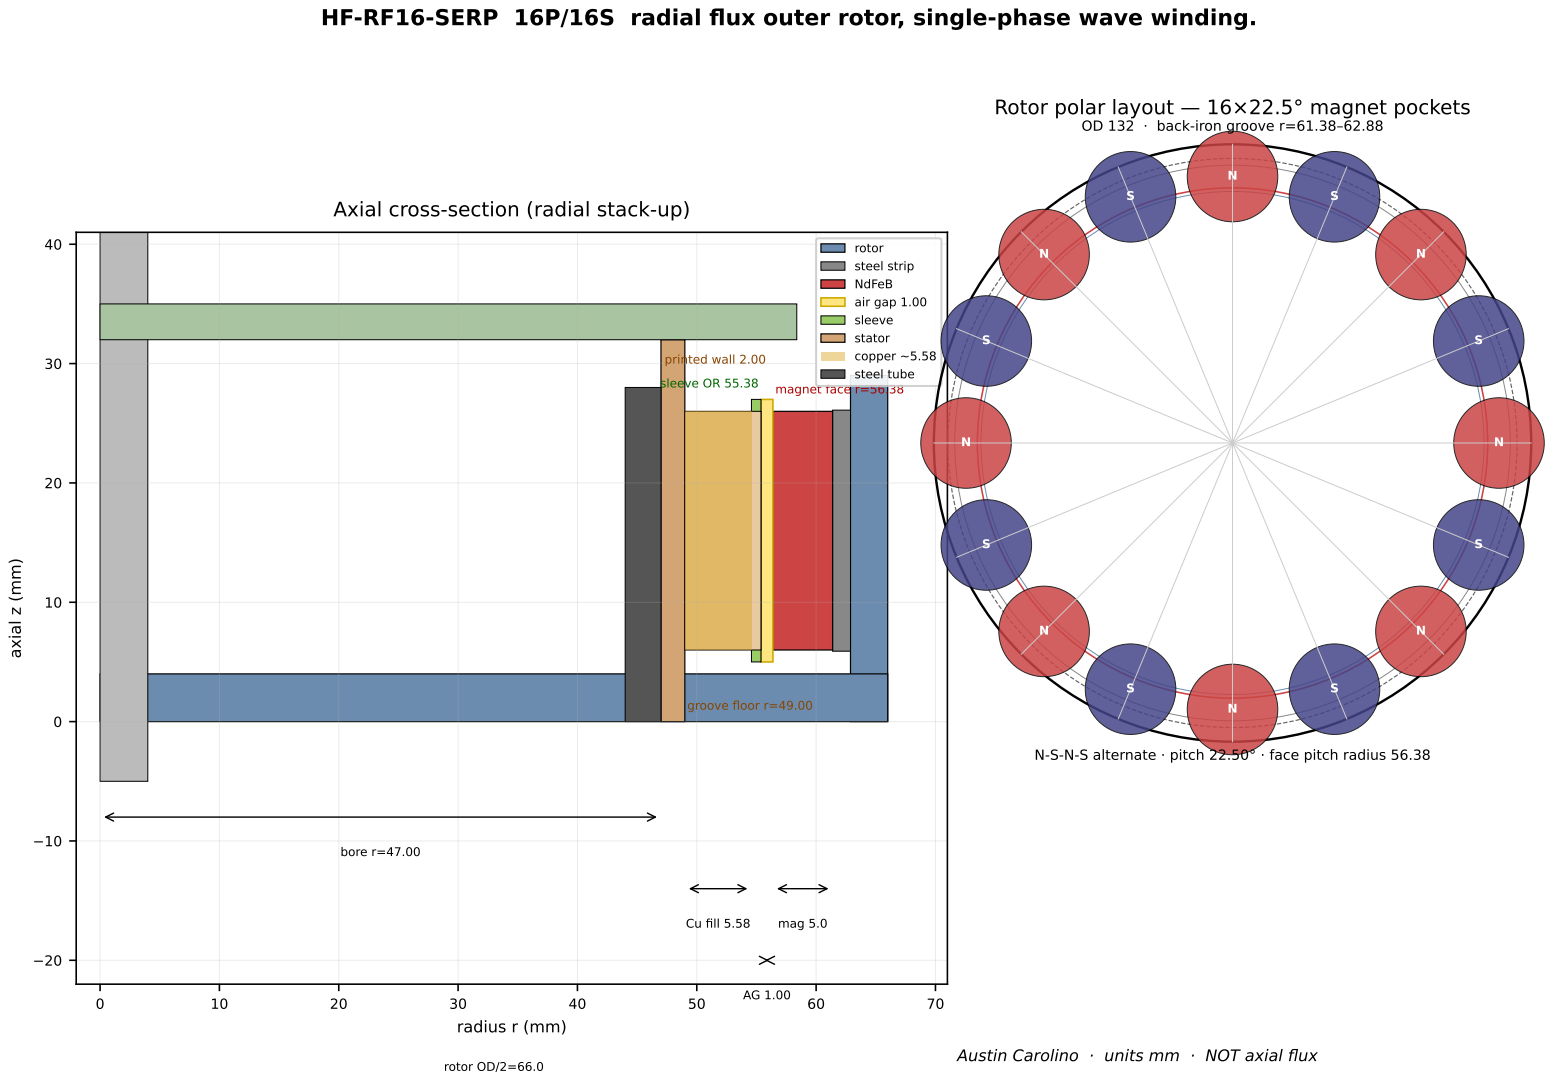
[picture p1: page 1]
radius r (mm); axial z (mm); bore r=47.00; Cu fill 5.58; mag 5.0; rotor OD/2=66.0; groove floor r=49.00

HF-RF16-SERP 16P/16S radial flux outer rotor, single-phase wave winding.

OD 132 · back-iron groove r=61.38–62.88

printed wall 2.00 | | rotor steel strip NdFeB air gap 1.00 sleeve stator copper ~5.58

OR 55.38 magnet face r=56.38 sleeve | steel tube

N-S-N-S alternate · pitch 22.50° · face pitch radius 56.38

Austin Carolino · units mm · NOT axial flux

N | S | N | S | N | S | N | S | N | S | N | S | N | S | N | S

Magnets (rotor) — polarity above axial runs · serpentine pitch = pole pitch = 22.5°

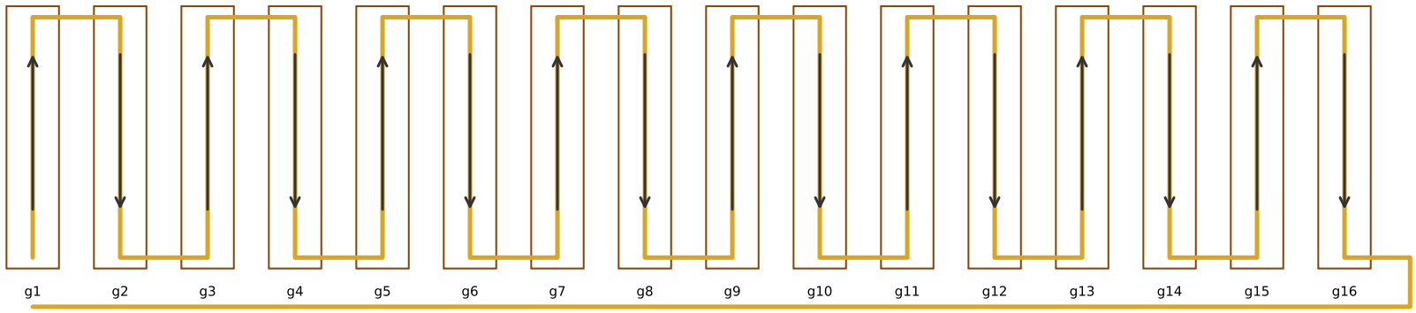
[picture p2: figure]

26 AWG wave winding · target 80–120 turns · tails out cap · bridge + ≥1000 µF

### Unrolled 16-slot square-wave / serpentine winding

Parameter | Value
MAG_COUNT | 16
Pole/slot pitch | 22.50°
Magnet face radius | 56.38
Magnet back radius | 61.38
Air gap | 1.00
Sleeve outer / inner r | 55.38 / 54.58
Bore diameter (radius) | 94.00 (47.00)
Groove floor radius | 49.00
Printed wall bore→floor | 2.00
Copper radial fill | 5.58
Groove / land arc @55.38 | 12.00 / 9.75
Rotor OD | 132.00
Steel strip cut length | 386

### Key dimensions (mm) — resolved geometry

CONFLICT: Original notes had drum bore r=47.00 with groove floor r=47.38, leaving only 0.38 mm printed wall (below the ≥2.00 mm minimum). Copper fill quoted as ~7.2 mm was inconsistent with a corrected sleeve outer r=55.38.

RESOLUTION (preferred):
- Magnet face r = 56.38, air gap = 1.00 exactly (≤1.2).
- Sleeve OUTER r = 55.38, wall = 0.80 → INNER r = 54.58.
- Bore RADIUS = 47.00 (diameter 94.00) for steel flux-return tube OD≈94.
- Groove floor r = 49.00 → printed wall = 2.00 mm.
- Copper radial fill = 55.38 − 0.80 − 49.00 = 5.58 mm (revises “7.2”).
- Groove open at r=55.38 before sleeve; land/groove arcs 9.75 / 12.00 at
that radius sum to pitch arc 21.75 mm (16×22.5°) — no ±0.5 adjustment needed.
- Legacy BOM “steel tube OD~47” referred to the bore RADIUS figure; corrected tube OD≈94 mm wall~3 length~28 to match Ø94 bore.

### Geometry conflict resolution

Qty | Item | Notes
16 | NdFeB Ø20×5 | axially magnetized, N-S alt.
1 | Steel strip 1.50×20.00×386 | mild steel back-iron
1 | Steel tube OD≈94 wall~3 L~28 | flux return (bore Ø94)
2 | 608ZZ bearing | 22×8×7
1 | Shaft Ø8 | through both bearings
— | M3 screws / heat-set inserts | rotor 6×; stator/cap 4×
— | M2 or snaps | sleeve clips
1 spool | 26 AWG magnet wire | serpentine 80–120 turns
4 | Diodes (bridge) | full-wave rectifier
1 | Capacitor ≥1000 µF | DC filter
1 | HF-RF16-ROTOR.stl | PETG/ABS/ASA/nylon
1 | HF-RF16-STATOR.stl | grooves UP
1 | HF-RF16-SLEEVE.stl | 2×180° shells
1 | HF-RF16-CAP.stl | bearing + grommets

### Hardware BOM (bought) + key printed parts

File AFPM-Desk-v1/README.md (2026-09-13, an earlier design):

# Generator Experiments v1 — AFPM-Desk Learning Generator

**Owner:** Austin Carolino
**Purpose:** Desktop educational build for **magnetic electricity production via Faraday induction** (generator / alternator principles).
**Not a free-energy / overunity device.** Output energy comes only from mechanical work you put in (hand crank or small motor). Orthodoxy: Maxwell–Faraday induction only.

## What this is

**AFPM-Desk-v1** is a **hand-crank axial-flux permanent-magnet (AFPM) learning generator**:

- One 3D-printed **rotor disk** carries **8× N42 neodymium discs** in alternating N/S polarity.
- A fixed **stator** holds **6 coils** of magnet wire facing the rotor across a small air gap.
- Turning the crank changes magnetic flux through the coils → induced EMF (AC).
- A bridge rectifier makes low-voltage DC for LEDs / measurement.

Desk-scale targets: measurable volts, LED loads, multimeter experiments — not household power.

## Package contents

| Path | Description |
|---|---|
| `DEBRIEF.md` | Parts, BOM, assembly, physics notes, measurements, failure modes |
| `SCHEMATIC.md` | Wiring, magnet polarity layout, ASCII diagrams |
| `schematics/wiring_polarity.svg` | Vector schematic |
| `stl/*.stl` | All 3D-printable parts |
| `scad/*.scad` | OpenSCAD sources (editable) |
| `README.md` | This overview |

## Printable parts (STL)

- `base_plate.stl` — desk base with bearing posts + stator pillars
- `rotor_disk.stl` — magnet pockets + polarity etch marks
- `stator_mount.stl` — 6 coil pockets + wire channels
- `shaft_hub.stl` — couples 8 mm shaft to rotor
- `hand_crank.stl` / `crank_handle.stl` — drive
- `bearing_cap.stl` — retaining caps (print 2)
- `coil_former.stl` — winding jig
- `electronics_tray.stl` — rectifier / LED bay
- `magnet_polarity_jig.stl` — N/S placement aid
- `spacer_ring.stl` — 1 mm air-gap spacers (print several)

## Quick start

1. Read **DEBRIEF.md** (safety first — neo magnets pinch and shatter).
2. Print STLs (PLA/PETG, 0.2 mm layers, ≥3 perimeters for rotor/base).
3. Buy BOM items (N42 20×3 mm discs, 28 AWG magnet wire, 608 bearings, etc.).
4. Wind 6 coils (~200 turns each), assemble per DEBRIEF, set **~2–3 mm air gap**.
5. Measure open-circuit AC with a multimeter while cranking; then rectifier → LED.

## Expected learning payoff

- Feel **cogging** as magnets pass coils.
- See **AC** frequency scale with RPM; rectified DC lights LEDs.
- Compare measured V vs Faraday estimates in DEBRIEF.
- Vary air gap / RPM / series-parallel coil wiring and watch EMF change.

## Physics stance (explicit)

This converts **mechanical energy → electrical energy**. Friction, copper I²R, and magnetic drag mean electrical out ≪ mechanical in. There is **no** claim of perpetual motion, free energy, or overunity.

## License / reproducibility

Open, reproducible educational design. Modify OpenSCAD parameters in `scad/parameters.scad` and re-render.

---
*Generator Experiments · Cycle 1 · v1*

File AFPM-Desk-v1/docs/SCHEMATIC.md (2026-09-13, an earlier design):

# SCHEMATIC — AFPM-Desk-v1 Wiring & Magnet Polarity

Educational Faraday-induction generator. Low-voltage only. No mains.

---

## 1. Magnet polarity layout (rotor face view)

Looking at the **magnet face** of `rotor_disk` (pockets toward you).  
8 magnets on PCD 70 mm. **Alternate N / S.**

```
                 M1 (N)
                   |
          M8 (S)   |   M2 (S)
             \     |     /
              \    |    /
               \   |   /
        M7 (N) -----●----- M3 (N)
               /   |   \
              /    |    \
             /     |     \
          M6 (S)   |   M4 (S)
                   |
                 M5 (N)
```

- Even indices in OpenSCAD (0,2,4,6) → **N** (bar etch on back of disk).  
- Odd indices (1,3,5,7) → **S** (cross etch).  
- Use `magnet_polarity_jig.stl` during epoxy.

**Rule:** Adjacent magnets must oppose. Same-facing neighbors cancel useful flux change.

---

## 2. Stator coil positions

6 coils, indexed C0…C5, angularly offset +30° from magnet zero so coils sit between pole centers at rest (reduces detent at park; still continuous EMF when spinning).

```
              C0
               |
        C5     |     C1
           \   |   /
            \  |  /
      C4 ---- ● ---- C2
            /  |  \
           /   |   \
        C3     |     
```

**Wind direction:** All coils wound the **same way** on the former (e.g. clockwise when viewing from rotor). Mark start (dot) and finish leads.

---

## 3. Recommended first wiring — series single string → bridge → LED

Simplest for first light:

```
  C0s ── C0f──┐
              ├── C1s ── C1f ──┐
                               ├── … (series all 6) …
                                              └── C5f ──●── AC1
  C0 start = AC2 ●──────────────────────────────────────┘

  AC1 ────┐         ┌──── (+) ─── 220–470Ω ─── LED ─── (−)
          │  BRIDGE │
  AC2 ────┤  RECT   ├──── (−) ─────────────────────────────┘
          └─────────┘
```

ASCII bridge (classic diamond):

```
          AC1
           │
      ┌────┴────┐
      │         │
     D1▷       ◁D2
      │         │
     (+)       (−)
      │         │
     D3▷       ◁D4
      │         │
      └────┬────┘
           │
          AC2
```

Diode orientation: cathodes of D1/D2 toward (+); anodes of D3/D4 toward (−).  
Module packages (W04M) already wire this; ~1.4 V total forward drop — significant at LED voltages, so series-aid coils matter.

---

## 4. Better educational wiring — 3-phase (v1 optional)

Group coils 120° apart:

| Phase | Coils (series) |
|---|---|
| A | C0 + C3 |
| B | C1 + C4 |
| C | C2 + C5 |

Connect phase finishes (or starts — be consistent) in **star (Y)**: join one end of A,B,C; take other ends to a **3-phase bridge** (or 6 discrete diodes).  
Star neutral can float for LED experiments.

Phase EMF ≈ 2× single-coil EMF (series aiding if wound same sense and spaced correctly).

---

## 5. Measurement taps

```
  [Coil string] ──┬── DMM ACV (open circuit)
                  │
                  ├── Bridge ── DMM DCV / LED load
                  │
                  └── Scope CH1 (optional AC waveform)
```

Tachometer on crank or phone RPM app on rotor mark.

---

## 6. Mechanical stack (side view)

```
   CRANK ═╤════ SHAFT ════╤═ HUB ═ ROTOR+MAGNETS
          │               │              ↕ air gap 2–3 mm
       BRG│            BRG│           STATOR+COILS
          │               │              │
        ══╧══ BASE PLATE ═╧══════════════╧══
                         │
                   ELECTRONICS TRAY (rectifier, LED)
```

---

## 7. Polarity check procedure

1. Spin slowly by hand with DMM on ACV across one coil.  
2. Note voltage.  
3. If series pair **decreases** V when connected, reverse one coil’s leads (series opposing → fix to series aiding).

---

## 8. SVG

See also `schematics/wiring_polarity.svg` for a printable diagram.

---
*End SCHEMATIC — AFPM-Desk-v1*

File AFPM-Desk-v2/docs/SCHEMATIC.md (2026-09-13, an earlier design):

# SCHEMATIC — AFPM-Desk-v2 Polarity, Wiring, Stack

Low-voltage educational Faraday generator. No mains.

---

## 1. Mechanical stack (side view, shaft horizontal)

```
  CRANK ══╤════ SHAFT ═══════════════════════════════╤══
          │                                           │
         BRG                                         BRG
          │                                           │
         H1                                           H2
          │                                           │
     STEEL-A                                         STEEL-B
     ROTOR-A  ▓▓▓ N/S magnets facing ──►    ◄── magnets S/N ▓▓▓  ROTOR-B
          │         ↕ air ~2 mm                 ~2 mm ↕        │
          │              ║ STATOR + 6 COILS ║                  │
          │              ║   (coreless)     ║                  │
          └──────────────╨──── pillars ────╨──────────────────┘
                              BASE FRAME
                                 │
                          ELECTRONICS TRAY
```

Flux (aligned pole): `steel-A → mag-A → air → coil → air → mag-B → steel-B` with circumferential return in each back-iron between adjacent poles.

---

## 2. Facing polarity rule

At angular station \(i\):

| Rotor | Facing stator |
|---|---|
| A, even \(i\) | **N** |
| A, odd \(i\) | **S** |
| B, even \(i\) | **S** (opposite of A) |
| B, odd \(i\) | **N** |

```
        Rotor A face (toward stator)          Rotor B face (toward stator)
                 M0 N                                    M0 S
              M7 S   M1 S                             M7 N   M1 N
                 \   /                                   \   /
           M6 N ---●--- M2 N                       M6 S ---●--- M2 S
                 /   \                                   /   \
              M5 S   M3 S                             M5 N   M3 N
                 M4 N                                    M4 S
```

Adjacent on same rotor: always alternate. Across gap: always attract (N↔S).

---

## 3. Coil layout

6 coils C0…C5 at angles \(30° + i\cdot 60°\) (offset from magnet zero).

```
              C0
               |
        C5     |     C1
           \   |   /
      C4 ---- ● ---- C2
           /   |   \
        C3     |
```

Wind all coils the **same sense**. Mark start (•) and finish.

---

## 4. Recommended first wiring — one phase → bridge → LED

Phase A = C0 + C3 in series (180° apart, same polarity sense when aiding):

```
  C0• ── C0f ── C3• ── C3f ──●── AC1
  C0 start tied after verifying aiding ……………●── AC2   (adjust)

  AC1 ──┐         ┌── (+) ── 220–470Ω ── LED ── (−)
        │ BRIDGE  │
  AC2 ──┤ RECT    ├── (−) ────────────────────────┘
        └─────────┘
```

Bridge diamond:

```
        AC1
         │
    ┌────┴────┐
   D1▷       ◁D2
    │         │
   (+)       (−)
    │         │
   D3▷       ◁D4
    └────┬────┘
         │
        AC2
```

---

## 5. Full 3-phase (educational upgrade)

| Phase | Coils series |
|---|---|
| A | C0 + C3 |
| B | C1 + C4 |
| C | C2 + C5 |

Star (Y): join one end of A,B,C; other ends → 3-phase bridge (or 6 diodes).  
Verify each series pair is **aiding** before starring.

---

## 6. Mermaid — energy flow

```mermaid
flowchart LR
  Hand[Hand crank τω] --> Shaft
  Shaft --> Rotors[Dual rotors + Neos + steel]
  Rotors -->|dΦ/dt| Coils[Stator coils]
  Coils -->|AC EMF| Rect[Bridge]
  Rect --> LED[LED load]
  Coils -->|Lenz drag| Rotors
```

---

## 7. Polarity check

1. Spin slowly; DMM ACV on one coil.  
2. Add second coil in series — V should **rise**. If it falls, reverse one lead.  
3. Repeat for each phase pair.

---
*End SCHEMATIC — AFPM-Desk-v2*

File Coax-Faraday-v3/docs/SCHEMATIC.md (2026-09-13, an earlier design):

# SCHEMATIC — Polarity & Wiring (v3)

## Mechanical topology

```
        rotating together (ROTOR)              fixed (STATOR)
   ┌─────────────────────────────┐         ┌──────────────┐
   │ Outer drum  Ø20×5  (N/S)in  │         │              │
   │         ↓ radial flux        │←—gap—→ │  Copper coil │←—gap—→ Inner drum Ø20×5 (N/S)out
   │                              │         │   bobbin     │
   └────────── shaft_hub / end_cap / shaft ─┴──────────────┘
                         608 bearings on base
```

Outer + inner mechanically locked via `shaft_hub` + `rotor_end_cap` on common Ø8 shaft.  
Coil cylinder bolted to base — **no brushes**.

---

## Polarity map (P=8)

View along +shaft. Stations every 45°.

```
        0° OUTER:N-in     INNER:N-out
       /    \
  315° S     N 45°
       |  COIL |
  270° N     S 90°
       \    /
      225°   135°
        180° OUTER:N-in   INNER:N-out
```

**Rule:** at each station, outer face polarity = inner face polarity (both toward coil), then **alternate** around the circle.  
Flux path: outer face → radial through coil → inner face → return via adjacent opposite pole pair.

Use `polarity_jig.stl`: tall peg = N seat, short peg = S seat (or label with marker).

---

## Coil wiring (single-phase — default)

Wind the stator window as **one continuous coil** (or P concentrated sectors **in series**, same sense relative to alternating poles).

```
[Coil start]----+----[Bridge ~]----+----[100 Ω]----[LED+]
                |                  |
[Coil end]------+----[Bridge ~]    +----[LED−]----gnd/return
                     [Bridge +]--------------------┘
                     [Bridge −]---- system return
```

- Bridge: W04M/W04G or 4×1N4007  
- LED: 2 V class; series **100 Ω** (tune 47–220 Ω)  
- For Voc measurement: disconnect LED; measure AC across coil or DC after bridge

**Series sectors (optional):** 8 slots → connect so voltages add at the electrical frequency \(f=\mathrm{RPM}/60\cdot P/2\).

---

## 3-phase (optional, not required)

If you wind 3 groups at 120° electrical (for P=8, 60° mechanical between groups):

```
  A ──┐
  B ──┼── star or delta ──→ 3-ph bridge → DC rail
  C ──┘
```

v3 BOM/sim assume **single-phase** for simplicity.

---

## Desk-safe notes

- Open-circuit volts are low (single-digit to low teens at hand crank)  
- Do **not** connect to mains  
- Shorted coil while cranking → strong drag + heating

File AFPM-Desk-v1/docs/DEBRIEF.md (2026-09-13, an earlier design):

# DEBRIEF — Generator Experiments v1 (AFPM-Desk)

**Build name:** AFPM-Desk-v1  
**Type:** Hand-crank **axial-flux permanent-magnet** educational generator  
**Physics basis:** Faraday’s law of induction (orthodox; not free-energy)  
**Audience:** Austin Carolino — desktop learning build  
**Date package:** 2026-09-07 (America/New_York)

---

## 1. Why this design (selection rationale)

Candidates considered:

| Option | Pros | Cons for desk v1 |
|---|---|---|
| Brushed DC motor as dynamo | Cheap, fast | High RPM needed; weak educational “magnet+coil” story |
| Faraday disk (homopolar) | Historic | Tiny volts; brush noise; hard LED demo |
| Reciprocating coil+magnet | Simple | Pulsed, low average power, awkward crank coupling |
| **Axial-flux PM (chosen)** | Clear flux change, 3D-printable, LEDs at hand speed, classic DIY pedagogy | Magnet pinch hazard; coil winding time |

**Chosen:** single-rotor / single-stator **axial-flux PM generator** with hand crank, optional small DC-motor drive later. Dual-rotor sandwich is a natural v2 upgrade (higher B_g).

Educational payoff: visible magnet polarity pattern, measurable AC vs RPM, cogging feel, rectifier → LED, compare measurements to Faraday estimates below.

---

## 2. Parts identified (labeled)

| Label | Part | Role |
|---|---|---|
| R1 | `rotor_disk.stl` | Carries 8 N42 discs; rotates; provides changing B |
| S1 | `stator_mount.stl` | Holds 6 coils fixed relative to base |
| B1 | `base_plate.stl` | Desk frame; bearing posts; stator pillars |
| H1 | `shaft_hub.stl` | Couples 8 mm shaft ↔ rotor |
| C1/C2 | `hand_crank.stl` + `crank_handle.stl` | Human mechanical input |
| BRG | 2× 608 bearings | Low-friction shaft support |
| CAP | `bearing_cap.stl` ×2 | Bearing retention |
| CF | `coil_former.stl` | Winding jig for ~200-turn coils |
| ET | `electronics_tray.stl` | Rectifier + LED / jacks |
| JIG | `magnet_polarity_jig.stl` | Ensures alternating N/S |
| SP | `spacer_ring.stl` | Sets ~2–3 mm air gap during setup |
| M1–M8 | N42 Ø20×3 mm Neo discs | Permanent magnet poles |
| W1–W6 | Magnet-wire coils | EMF pickup (Faraday) |
| SHAFT | Ø8×~180 mm steel rod | Mechanical axis |
| RECT | W04M / DB107 bridge | AC→DC for LEDs |
| LOAD | LEDs + series resistor | Visible output |

---

## 3. Bill of materials (approximate sources / USD)

Prices are ballpark US hobby retail (Amazon / Digi-Key / McMaster / local hardware), 2026 order of magnitude.

| Qty | Item | Spec | Approx. | Notes |
|-----|---|---|---|---|
| 8 | Neo disc magnets | **N42**, Ø20 mm × 3 mm, Ni-plated | $8–15 / pack | Prefer N42; N52 OK but stronger pinch |
| 1 spool | Magnet wire | **28 AWG** enameled Cu, ≥100 m | $10–15 | 26 AWG = fewer turns / lower V |
| 2 | Ball bearings | **608-2RS** (8×22×7 mm) | $3–6 | Skateboard bearings |
| 1 | Shaft | Steel rod Ø8 mm × 180–200 mm | $3–8 | Cut + deburr |
| 4 | Set screws | M3 × 6 mm | $2 | Hub + crank |
| 8 | Screws | M3 × 12 mm + nuts | $2 | Hub↔rotor |
| 3 | Screws | M4 × 35 mm + nuts/standoffs | $3 | Stator↔base pillars |
| 1 | Bridge rectifier | 1 A / 50–400 V (W04M etc.) | $1–2 | Overkill voltage OK |
| 5–10 | LEDs | 5 mm red/green + 220–470 Ω resistors | $2 | Load demo |
| 2 | Banana jacks (opt.) | Panel 4 mm | $3 | Measurement |
| 1 | Multimeter | Any DMM with ACV/DCV | — | Essential |
| — | Filament | PLA or PETG ~150–200 g | $5 | All STLs |
| 1 | Cyanoacrylate / epoxy | Gel CA or 5-min epoxy | $5 | Magnet + coil potting |
| 1 | Kapton / electrical tape | — | $3 | Coil finishing |
| 1 | Eye protection | Safety glasses | — | **Required** with Neos |

**Total hardware (excl. printer/meter):** roughly **$45–80**.

---

## 4. Geometry assumptions (as printed)

From `scad/parameters.scad`:

- Rotor OD 100 mm; magnet PCD 70 mm; **8 poles**
- Magnets Ø20 × 3 mm in pockets ~3.2 mm deep
- Stator OD 110 mm; **6 coil** pockets on PCD 70 mm
- Shaft Ø8 mm; bearings 608
- Design mechanical **air gap** target: **2.0–3.0 mm** (rotor face ↔ coil face)
- Coil former core ≈ racetrack ~14×26 mm, wind height ~10–11 mm → ~200 turns of 28 AWG is realistic

---

## 5. Physics notes (double-checked, orthodox)

### 5.1 Faraday’s law

\[
\mathcal{E} = -N \frac{d\Phi_B}{dt}
\]

For approximately sinusoidal flux through one coil:

\[
\Phi(t) \approx \Phi_{\mathrm{peak}} \sin(2\pi f t), \quad
\mathcal{E}_{\mathrm{peak}} \approx N \cdot 2\pi f \cdot \Phi_{\mathrm{peak}}
\]

\[
\mathcal{E}_{\mathrm{rms}} \approx \frac{\mathcal{E}_{\mathrm{peak}}}{\sqrt{2}}
\]

Electrical frequency for an alternator with \(P\) poles:

\[
f = \frac{\mathrm{RPM}}{60} \cdot \frac{P}{2}
\]

Here \(P = 8\) → \(f = (\mathrm{RPM}/60)\times 4\).

| RPM (hand/motor) | \(f\) (Hz) |
|---|---|
| 60 | 4 |
| 120 | 8 |
| 300 | 20 |
| 600 | 40 |

### 5.2 Magnet grade & air-gap flux (assumptions)

- **N42** NdFeB remanence \(B_r \approx 1.28\)–\(1.32\,\mathrm{T}\) (typical datasheet band).
- Single-sided rotor (no steel back-iron in v1 plastic disk): flux return is poor → **air-gap flux density facing a coil is much less than \(B_r\)**.
- Conservative working assumption for estimates:

\[
B_g \approx 0.25\text{–}0.40\,\mathrm{T}
\]

at ~2–3 mm gap over the magnet face (order-of-magnitude; measure with a gaussmeter if available). Adding a thin steel backing plate behind magnets (v1.1) raises \(B_g\) toward ~0.5 T — optional upgrade, increases cogging.

Magnet face area:

\[
A_m = \pi (0.010)^2 = 3.14\times 10^{-4}\,\mathrm{m}^2
\]

Peak flux linkage estimate per coil (magnet fully aligned; coupling factor \(k_c \approx 0.6\)–\(0.8\) for finite coil size):

\[
\Phi_{\mathrm{peak}} \approx k_c B_g A_m
\approx 0.7 \times 0.30 \times 3.14\times 10^{-4}
\approx 6.6\times 10^{-5}\,\mathrm{Wb}
\]

### 5.3 Turns & wire

- **28 AWG** diameter ≈ 0.32 mm bare; with enamel ~0.33–0.35 mm.
- ~200 turns fit on the coil former (verify by counting while winding).
- DC resistance per coil (length ≈ 200 × ~0.08 m mean turn ≈ 16 m):

\[
R_{\mathrm{coil}} \approx 16\,\mathrm{m} \times 0.213\,\Omega/\mathrm{m} \approx 3.4\,\Omega
\]

(28 AWG ≈ 0.213 Ω/m at 20 °C — use datasheet if available.)

### 5.4 Expected EMF (order of magnitude)

One coil at **120 RPM** (\(f=8\,\mathrm{Hz}\)):

\[
\mathcal{E}_{\mathrm{peak,1}} \approx 200 \times 2\pi \times 8 \times 6.6\times 10^{-5}
\approx 0.66\,\mathrm{V}
\]

\[
\mathcal{E}_{\mathrm{rms,1}} \approx 0.47\,\mathrm{V}
\]

Wiring options:

1. **All 6 coils in series (single-phase style, educational):**  
   Open-circuit \(\mathcal{E}_{\mathrm{rms,total}} \sim 2.5\)–\(4\,\mathrm{V}\) at ~120 RPM (phases don’t peak together — treat as rough; expect **~1.5–3 Vrms** measured depending on series phasing).  
   Better: wire as **3-phase** (two coils series per phase, 120° spatial) then 3-phase bridge; phase EMF ~ **0.8–1.5 Vrms** @ 120 RPM, more at higher RPM.

2. **Practical desk targets:**
   - Hand crank ~60–150 RPM → **~0.5–4 V** open-circuit AC (config dependent), enough to **flash/light LEDs** after rectification if series stacking is correct.
   - Small DC motor / drill at 300–600 RPM → roughly **linear scale with RPM**: expect **several volts** OC; still keep loads LED-scale.

**Current:** short-circuit / LED current limited by coil R and rectifier. Expect **tens of mA** into LEDs at hand speed — measurable, not hazardous. Do **not** connect to mains or battery banks without proper engineering (out of scope).

### 5.5 Power & energy honesty

Mechanical input power \(P_{\mathrm{mech}} = \tau\omega\). Electrical output \(P_{\mathrm{elec}} = VI\) with \(\eta < 1\) due to copper loss, bearing friction, windage, hysteresis/eddy if steel added. **Electrical energy out never exceeds mechanical energy in.**

---

## 6. Safety

1. **Neodymium pinch hazard** — fingers can be blood-blistered between magnets or magnet↔steel. Slide magnets into pockets; never let two free magnets slam.
2. **Eye protection** — Neos can chip; plating shards are sharp.
3. **Keep away from pacemakers, magstripe cards, HDDs, phones** during handling.
4. **No mains wiring** — this is isolated low-voltage educational gear only.
5. **Drill drive caution** — if chucking the shaft in a drill, use low speed; overspeed increases voltage and mechanical risk (rotor imbalance).
6. **Children** — adult supervision; magnets are ingestion hazard (medical emergency if swallowed).

---

## 7. Assembly steps

1. **Print** all STLs; clean magnet pockets and bearing seats.
2. **Press 608 bearings** into base posts; add bearing caps loosely.
3. **Mark polarity** of each N42 with a known reference magnet; use `magnet_polarity_jig`.
4. **Epoxy magnets** into rotor pockets with **alternating N/S** (even indices N, odd S as etched). Cure fully.
5. **Bolt shaft hub** to rotor; slide onto shaft; set-screw hub.
6. **Wind 6 coils** on former: ~200 turns 28 AWG; leave 15 cm leads; tape; carefully remove from split former.
7. **Sand enamel** off lead ends; tin with solder.
8. **Seat coils** in stator pockets (same wind direction for series stacking); hot-glue or epoxy lightly.
9. **Mount stator** on base pillars with M4; use `spacer_ring` stack to set **2–3 mm** gap to magnet faces; verify spin clearance (**no scrape**).
10. **Install crank** on shaft end; check smooth rotation and cogging.
11. **Wire** per `SCHEMATIC.md` (start: all coils series → bridge → LED+resistor).
12. **First test:** multimeter ACV while cranking; then connect LED load.

---

## 8. What to measure

| Measurement | Instrument | Expectation |
|---|---|---|
| Open-circuit \(V_{\mathrm{ac}}\) vs RPM | DMM ACV + tach/phone RPM | Roughly ∝ RPM |
| Frequency | Scope / phone scope app | \(f = 4\times(\mathrm{RPM}/60)\) |
| Rectified \(V_{\mathrm{dc}}\) no load | DMM DCV | ~0.9× peak AC minus diode drops |
| LED current | DMM mA series | Tens of mA hand speed |
| Coil resistance | DMM Ω | ~3–5 Ω each |
| Air gap | Feeler / calipers | 2–3 mm |
| Cogging torque feel | Hand | Stronger if gap shrinks / steel back-iron added |

Lab notebook prompt: plot \(V_{\mathrm{oc}}\) vs RPM; compare slope to Faraday estimate.

---

## 9. Failure modes

| Symptom | Likely cause | Fix |
|---|---|-----|
| No voltage | Enamel not stripped; open coil; wrong meter mode | Continuity check; use ACV |
| Tiny voltage | Huge air gap; magnets same polarity; few turns | Gap 2–3 mm; re-check N/S; recount turns |
| Rotor scrapes | Gap too small; warped print | Add spacers; re-level stator |
| Harsh cogging / won’t turn | Magnets attracted to steel nearby; gap tiny | Remove ferrous clutter; increase gap |
| LED never lights | Series resistor too large; AC phase cancellation | Try one LED+220Ω on rectified DC; re-wire series aiding |
| Magnet flies out | Poor epoxy / no cure | Re-bond; optional pocket lip redesign |
| Bearing seize | Misalignment | Loosen posts; realign shaft |
| Shock from “high V” | Unlikely at hand RPM; possible with drill | Don’t lick terminals; still low energy |

---

## 10. v1.1 / v2 ideas (not in this package)

- Steel backing plate on rotor (higher \(B_g\))
- Dual rotor sandwich (flux through stator both sides)
- 3-phase rectifier PCB
- Belt drive from small DC motor with known RPM for calibration

---

## 11. Explicit non-claims

- Not a free-energy, zero-point, or overunity machine.  
- Not a substitute for utility power.  
- Magnet “self-running” myths are incompatible with Faraday induction + energy conservation as used here.

---
*End DEBRIEF — AFPM-Desk-v1*

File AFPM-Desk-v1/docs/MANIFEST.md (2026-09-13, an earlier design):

# AFPM-Desk-v1 local package manifest
Root: /workspace/magnet-cycle-1/generator-experiments/v1

- `DEBRIEF.md` (11691 bytes)
- `README.md` (3001 bytes)
- `SCHEMATIC.md` (4422 bytes)
- `afpm_desk_v1_full_package.tar.gz` (242981 bytes)
- `scad/base_plate.scad` (1902 bytes)
- `scad/bearing_cap.scad` (282 bytes)
- `scad/coil_former.scad` (614 bytes)
- `scad/crank_handle.scad` (289 bytes)
- `scad/electronics_tray.scad` (537 bytes)
- `scad/hand_crank.scad` (678 bytes)
- `scad/magnet_polarity_jig.scad` (778 bytes)
- `scad/parameters.scad` (978 bytes)
- `scad/rotor_disk.scad` (1335 bytes)
- `scad/shaft_hub.scad` (582 bytes)
- `scad/spacer_ring.scad` (262 bytes)
- `scad/stator_mount.scad` (1743 bytes)
- `schematics/wiring_polarity.svg` (5956 bytes)
- `stl/base_plate.stl` (558157 bytes)
- `stl/bearing_cap.stl` (123378 bytes)
- `stl/coil_former.stl` (173366 bytes)
- `stl/crank_handle.stl` (124564 bytes)
- `stl/electronics_tray.stl` (87451 bytes)
- `stl/hand_crank.stl` (199096 bytes)
- `stl/magnet_polarity_jig.stl` (142527 bytes)
- `stl/rotor_disk.stl` (629426 bytes)
- `stl/shaft_hub.stl` (399683 bytes)
- `stl/spacer_ring.stl` (82149 bytes)
- `stl/stator_mount.stl` (516092 bytes)
- `stl_gz/base_plate.stl.gz` (40946 bytes)
- `stl_gz/bearing_cap.stl.gz` (8464 bytes)
- `stl_gz/coil_former.stl.gz` (11644 bytes)
- `stl_gz/crank_handle.stl.gz` (8856 bytes)
- `stl_gz/electronics_tray.stl.gz` (6028 bytes)
- `stl_gz/hand_crank.stl.gz` (15894 bytes)
- `stl_gz/magnet_polarity_jig.stl.gz` (9603 bytes)
- `stl_gz/rotor_disk.stl.gz` (44795 bytes)
- `stl_gz/shaft_hub.stl.gz` (29374 bytes)
- `stl_gz/spacer_ring.stl.gz` (5649 bytes)
- `stl_gz/stator_mount.stl.gz` (41777 bytes)

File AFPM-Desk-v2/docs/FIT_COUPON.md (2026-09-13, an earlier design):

# FIT_COUPON — Print Before the Generator

File: `stl/fit_coupon.stl` · Source: `scad/fit_coupon.scad`

## Why

FDM holes shrink; bearing press fits are printer-specific. One 80×50×6 mm coupon saves wasted rotors.

## What’s on the coupon

1. **Shaft hole ladder** — Ø8.2, 8.3, 8.4, 8.5 mm (approx.)  
2. **Bearing pocket variants** — three 608 OD seats with slight interference steps  
3. **Magnet pocket** — Ø20.25 × depth ~3.15 mm  
4. **M3 clearance + tap pilot**

## Procedure

1. Print in the **same material/profile** you’ll use for rotors (PETG recommended).  
2. Test Ø8 rod: choose slip that spins freely without slop → set `clearance_slip` in `parameters.scad`.  
3. Press 608 into the pocket that holds firmly without cracking → set `press_interference` / `bearing_seat_od`.  
4. Drop N42 into magnet pocket: snug, flush or 0.1–0.2 mm proud OK → adjust `magnet_pocket_xy` / `magnet_pocket_z`.  
5. Re-render STLs if you changed parameters:

```bash
cd /workspace/generator-experiments/v2
openscad -o stl/rotor_disc_A.stl --export-format=binstl scad/rotor_disc_A.scad
# …repeat for affected parts
```

6. Only then print RA/RB/base_frame.

---
*End FIT_COUPON*

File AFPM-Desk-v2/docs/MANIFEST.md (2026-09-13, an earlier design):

# MANIFEST — Generator Experiments v2

**Build:** AFPM-Desk-v2 Dual-Rotor Sandwich  
**Created:** 2026-09-10 (America/New_York)  
**Root:** `/workspace/generator-experiments/v2/`

## Documentation

| File | Description |
|---|---|
| README.md | Overview, topology choice, quick start |
| BUILD.md | Assembly instructions |
| PARTS.md | Labeled parts, BOM, per-part debrief |
| SCHEMATIC.md | Polarity, wiring, stack diagrams |
| PHYSICS.md | Faraday estimates, citations, non-claims |
| PRINT_NOTES.md | Kobra 3 Max orientation / supports / pause |
| FIT_COUPON.md | Clearance coupon procedure |
| MANIFEST.md | This file |

## OpenSCAD (`scad/`)

parameters.scad, rotor_disc.scad, rotor_disc_A.scad, rotor_disc_B.scad, stator_plate.scad, base_frame.scad, shaft_hub.scad, coil_former.scad, coil_bobbin.scad, hand_crank.scad, crank_handle.scad, bearing_cap.scad, spacer_ring.scad, spacer_1mm.scad, spacer_1p5mm.scad, spacer_2mm.scad, magnet_polarity_jig.scad, electronics_tray.scad, stator_clamp.scad, fit_coupon.scad

## Binary STLs (`stl/`)

fit_coupon, rotor_disc_A, rotor_disc_B, stator_plate, base_frame, shaft_hub, coil_former, coil_bobbin, hand_crank, crank_handle, bearing_cap, spacer_1mm, spacer_1p5mm, spacer_2mm, magnet_polarity_jig, electronics_tray, stator_clamp

## Regenerate STLs

```bash
cd /workspace/generator-experiments/v2
bash scripts/export_stls.sh
```

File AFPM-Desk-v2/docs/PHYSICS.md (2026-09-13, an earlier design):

# PHYSICS — AFPM-Desk-v2 Dual-Rotor Sandwich

Educational estimates only. Assumptions stated. **Reject perpetual-motion claims.**

---

## 1. Governing law (Faraday / Lenz)

\[
\mathcal{E} = -N \frac{d\Phi_B}{dt}
\]

Lenz’s law: induced current opposes the flux change that produces it → **magnetic drag** when loaded. You feel that drag in the crank; it is the mechanical power being converted (plus losses).

For approximately sinusoidal flux through one coil:

\[
\Phi(t) \approx \Phi_{\mathrm{peak}}\sin(2\pi f t)
\quad\Rightarrow\quad
\mathcal{E}_{\mathrm{peak}} \approx N\cdot 2\pi f\cdot\Phi_{\mathrm{peak}}
\]

\[
\mathcal{E}_{\mathrm{rms}} \approx \mathcal{E}_{\mathrm{peak}}/\sqrt{2}
\]

Electrical frequency for \(P\) poles:

\[
f = \frac{\mathrm{RPM}}{60}\cdot\frac{P}{2}
\]

Here \(P = 8\) (same pole count as v1 on each rotor) → \(f = 4\times(\mathrm{RPM}/60)\).

| RPM | \(f\) (Hz) |
|-----|---|
| 60  | 4 |
| 90  | 6 |
| 120 | 8 |
| 300 | 20 |

(Refs: standard synchronous-machine frequency relation; AFPM modelling e.g. Gieras et al.; Energies 2020 “Modeling of Axial Flux Permanent Magnet Generators” [MDPI Energies 13(21):5741](https://www.mdpi.com/1996-1073/13/21/5741).)

---

## 2. Why dual-rotor + steel back-iron raises \(B_g\)

**v1 problem:** single plastic rotor → flux return through air/plastic → large reluctance → \(B_g\) facing coils ≪ \(B_r\).

**v2 path:**

```
[steel A][magnet A] --air-- [coil] --air-- [magnet B][steel B]
```

- Facing magnets at the same angular station are **opposite polarity** (N on A faces S on B) so axial flux threads the coil.
- Adjacent magnets on one rotor **alternate** N/S.
- **Steel back-iron** (mild steel, µ_r ≫ 1) gives a low-reluctance path between adjacent poles on each rotor, concentrating useful gap flux (classic SSDR / dual-rotor AFPM; see also Latoufis et al. rural AFPM design notes; Habib et al. SSDR coreless comparisons, AEJ 2024).

**N42 remanence:** typical datasheet \(B_r \approx 1.28\)–\(1.32\,\mathrm{T}\) (e.g. manufacturer N42 bands). Gap flux is **not** \(B_r\).

---

## 3. Air-gap flux density assumptions (v2)

Magnetic non-steel path (order of magnitude):

| Segment | Thickness |
|---|---|
| Magnet A | 3 mm (source) |
| Mechanical air A | ~2 mm |
| Coil / plastic stator | ~8–10 mm effective |
| Mechanical air B | ~2 mm |
| Magnet B | 3 mm (source) |

Conservative **working assumption** for mid-coil flux density under a magnet face with dual N42 + steel:

\[
B_g \approx 0.40\text{–}0.60\,\mathrm{T}
\]

(Central estimate used below: **\(B_g = 0.50\,\mathrm{T}\)**.  
v1 used ~0.30 T. Dual + steel ≈ **~1.5–2×** coupling improvement — not infinite.)

If a gaussmeter is available, measure at mid-gap with stator removed / thin probe — revise Φ below.

Magnet face area (Ø20 mm):

\[
A_m = \pi (0.010)^2 = 3.14\times 10^{-4}\,\mathrm{m}^2
\]

Coupling factor coil vs magnet footprint \(k_c \approx 0.65\)–\(0.80\) (coil window ≠ magnet disc exactly):

\[
\Phi_{\mathrm{peak}} \approx k_c B_g A_m
\approx 0.75 \times 0.50 \times 3.14\times 10^{-4}
\approx 1.18\times 10^{-4}\,\mathrm{Wb}
\]

---

## 4. Turns & resistance

- Wire: **28 AWG** enameled Cu (~0.32 mm bare; ~0.213 Ω/m @ 20 °C typical).
- Target: **~200 turns / coil** on former (same as v1 skill).
- Mean turn length ≈ 0.08 m → length ≈ 16 m → \(R_{\mathrm{coil}} \approx 3.4\,\Omega\).

More turns → higher EMF **and** higher R (and harder to fit). Fewer turns (26 AWG) → lower V, higher current capability.

---

## 5. Open-circuit voltage estimates

### One coil @ 120 RPM (\(f = 8\,\mathrm{Hz}\))

\[
\mathcal{E}_{\mathrm{peak,1}} \approx 200 \cdot 2\pi \cdot 8 \cdot 1.18\times 10^{-4}
\approx 1.18\,\mathrm{V}
\]

\[
\mathcal{E}_{\mathrm{rms,1}} \approx 0.84\,\mathrm{V}
\]

### @ 60 RPM (\(f = 4\,\mathrm{Hz}\)) — scale ∝ RPM

\[
\mathcal{E}_{\mathrm{rms,1}} \approx 0.42\,\mathrm{V}
\]

### Wiring aggregates (rough)

| Config | Expectation @ 120 RPM OC |
|---|---|
| Single coil | ~0.7–1.0 Vrms |
| 2 coils series aiding (one phase) | ~1.4–2.0 Vrms |
| 3-phase star, phase-phase | ~2–4 Vrms (geometry/phasing dependent) |
| All 6 series (careful aiding) | ~3–6 Vrms possible; phase cancellation if wrong |

**Hand-crank band (60–120 RPM):** plan on **~1–8 Vrms** open-circuit depending on wiring — **LED-scale after rectification**, not utility voltage.

**Drill @ 300 RPM:** ~2.5× the 120 RPM numbers → still typically **low tens of volts max** if heavily series-stacked; treat as educational, not grid.

Diode bridge drops ~1.4 V (Si) — significant at LED voltages; Schottky helps.

---

## 6. Rough power

Loaded, \(P \approx V I\) with I limited by coil R + load.

Example: rectified ~3 V into LED string drawing 50 mA → \(P \approx 0.15\,\mathrm{W}\).  
Vigorous crank / better wiring / smaller gap → **~0.5–2 W** educational ballpark.  
With motor drive at higher RPM, a few watts possible — still **order of watts**, desk-safe energy.

**Energy honesty:**

\[
P_{\mathrm{elec}} < P_{\mathrm{mech}} = \tau\omega
\]

Copper loss \(I^2R\), bearing friction, windage, and (with steel) some eddy/hysteresis in back-iron all reduce η. Steel should be **thin** (1.5–2 mm) and preferably **laminated or low-carbon** to limit eddy; for hand RPM eddy is modest.

---

## 7. What dual-rotor does *not* do

- Does **not** create energy from magnets alone.
- Does **not** run itself from its own output (Lenz drag + losses).
- Does **not** violate Faraday or Kelvin–Planck.
- Stronger magnets / steel only improve **coupling** of the mechanical input you provide.

---

## 8. Citations & further reading

1. Faraday’s law — any intro EM text (Griffiths *Introduction to Electrodynamics*).
2. [Modeling of Axial Flux Permanent Magnet Generators](https://www.mdpi.com/1996-1073/13/21/5741) — Energies 13(21):5741 (2020): dual-rotor disc AFPM analytical models, coreless vs cored stator.
3. Latoufis et al., “Axial flux permanent magnet generator design for low cost manufacturing of small wind turbines” — practical DIY AFPM sizing (magnet grade, gap, turns). PDF: rurerg.net / related Scoraig/Otherpower lineage.
4. Habib et al., SSDR vs DSSR coreless AFPM prototype comparison — *Alexandria Engineering Journal* (2024): SSDR enables fully coreless path, higher power density for portable apps.
5. Analytical ironless AFPM sizing (N42 example parameters) — Electronics 2025, “Analytical Modeling of an Ironless Axial Flux Machine…” [MDPI Electronics](https://www.mdpi.com/2079-9292/14/14/2901).
6. N42 NdFeB typical \(B_r\) — manufacturer datasheets (e.g. 1.28–1.32 T).

Nuance: published AFPM papers often target kW wind machines; **scaling laws still apply**, but absolute V/I here are desk-learning, not turbine-rated.

---

## 9. Measurement plan (validate estimates)

1. Tach or phone RPM on rotor mark.
2. DMM ACV on one coil vs RPM → slope ∝ \(N\Phi\).
3. Scope frequency → confirm \(f = 4\cdot\mathrm{RPM}/60\).
4. Vary air gap with spacer rings → V falls as gap rises (reluctance).
5. Compare v1 single-rotor (if retained) vs v2 dual at same RPM/gap — expect higher V on v2.

Lab notebook: plot \(V_{\mathrm{oc}}\) vs RPM; annotate assumed \(B_g\).

---
*End PHYSICS — AFPM-Desk-v2*

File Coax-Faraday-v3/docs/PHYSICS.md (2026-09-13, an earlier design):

# PHYSICS — Coax Faraday v3

Educational estimates. **Reject perpetual motion / overunity / “magnets alone make free power.”**  
Mechanical work against Lenz drag → electrical energy (+ heat).

---

## 1. Governing equations

\[
\mathcal{E} = -N\frac{d\Phi_B}{dt}
\]

For approximately sinusoidal flux:

\[
\Phi(t)\approx\Phi_{\mathrm{peak}}\sin(2\pi f t)
\quad\Rightarrow\quad
\mathcal{E}_{\mathrm{peak}}\approx N\cdot 2\pi f\cdot\Phi_{\mathrm{peak}}
\]

\[
\mathcal{E}_{\mathrm{rms}}\approx\mathcal{E}_{\mathrm{peak}}/\sqrt{2}
\]

Electrical frequency for \(P\) poles:

\[
f=\frac{\mathrm{RPM}}{60}\cdot\frac{P}{2}
\]

Baseline \(P=8\) → \(f=4\times(\mathrm{RPM}/60)\). At 120 RPM, \(f=8\,\mathrm{Hz}\).

---

## 2. Magnet material (citations)

**Assumption:** magnets are **Ø20 mm × 5 mm axial discs**, grade **N42** preferred (N52 optional).

| Grade | Br (typical) | Hcb / Hcj (order) | Sources |
|---|---|---|---|
| **N42** | **1.28–1.32 T** (use **1.30 T**) | Hcb ~860–955 kA/m; Hcj ≥955 kA/m | [supermagnete S-20-05-N datasheet](https://www.supermagnete.nl/eng/data_sheet_S-20-05-N.pdf); [MPCO N42 20×5](https://mpcomagnetics.com/product/20-x-5mm-round-disk-neodymium-iron-boron-magnet-n42-ni/); [Newland typical properties](https://newlandmagnetics.eu/wp-content/uploads/2020/06/typical-magnetic-properties.pdf) |
| **N52** | **1.42–1.48 T** (use **1.44 T**) | lower Hcj than N42 (~876 kA/m min band) | [Arnold N52](https://www.arnoldmagnetics.com/wp-content/uploads/2017/11/N52-151021.pdf); [Eclipse NdFeB grades](https://www.eclipsemagnetics.com/site/assets/files/33708/em_ca_neodymium_grades_datasheet.pdf); [Goudsmit grades](https://www.goudsmitmagnetics.com/uploads/pdf/Neodymium_grades_available_at_Goudsmit_20250822_1547.pdf) |

Ø3×5 mm cans use the **same grade Br**; only geometry (area / permeance) changes.

Gap flux **≠ Br**. Remanence is a material property; useful \(B_g\) depends on reluctance of air gaps + coil path + leakage.

---

## 3. Topology & polarity

**Chosen:** outer + inner magnet drums **locked** → one rotor; **coil cylinder fixed** (stator).  
Justification: no brushes; radial flux through stationary copper; dual magnets raise \(B_g\); desk-safe.

**Polarity map (P=8):** looking along shaft, stations \(0^\circ,45^\circ,\ldots\):

| Angle | Outer face (toward coil) | Inner face (toward coil) |
|---|---|---|
| 0° | **N** (N-in) | **N** (N-out) |
| 45° | **S** | **S** |
| 90° | **N** | **N** |
| … | alternate | alternate |

Facing pair at each station: **like poles toward the coil** so flux goes outer→coil→inner (or reverse) **radially**, then returns azimuthally via adjacent opposite poles. Equivalent: treat each station as a radial “through-coil” pair with alternating sign around the circle.

---

## 4. Geometry & assumptions (baseline)

| Item | Value |
|---|---|
| Inner magnet face radius | 33 mm |
| Air gap each side | 2 mm (sweep 1–3 mm) |
| Coil radial depth | 9 mm |
| Outer magnet face radius | ≈46 mm |
| Magnet | Ø20×5 mm, \(A_m=\pi(0.01)^2=3.14\times10^{-4}\,\mathrm{m}^2\) |
| Axial active | ≈22–24 mm |
| Coupling \(k_c\) | 0.70 (dual) |
| Leakage / fringing factor in Bg model | ~0.55 (dual) |

**Bg model (dual):**

\[
B_g \approx B_r\cdot\frac{L_{m,\mathrm{eff}}}{L_{m,\mathrm{eff}}+g_{\mathrm{eff}}}\cdot k_{\mathrm{leak}}
\]

with \(L_{m,\mathrm{eff}}\approx 2\times5\,\mathrm{mm}\), \(g_{\mathrm{eff}}\approx 2\cdot\mathrm{gap}+\mathrm{coil\_radial}\).  
Baseline result: **\(B_g\approx0.31\,\mathrm{T}\)** (N42, 2 mm gaps).

\[
\Phi_{\mathrm{peak}}\approx k_c B_g A_m \approx 6.8\times10^{-5}\,\mathrm{Wb}
\]

**Single-magnet (no inner)** drops \(B_g\) and FoM roughly **2–3×** in this model — dual is worth the cogging.

---

## 5. Inner magnet choice (calculation)

| Option | P (fit) | Φ order | FoM \(P\cdot\Phi\) (sim) |
|---|---|---|---|
| Dual Ø20 inner + Ø20 outer | 8 | ~6.8e-5 Wb | **~5.5e-4** ← **WIN** |
| Dual Ø3 inner + Ø20 outer | up to 12 | ~1.5e-6 Wb | ~1.8e-5 |
| Outer only | 8 | ~2.5e-5 Wb | ~2.0e-4 |

**Pick Ø20×5 inner discs.** Smaller cans allow more poles in isolation, but outer Ø20 already sets P; area loss dominates.

**Tradeoffs acknowledged:** dual magnets raise \(B_g\) but increase **cogging / attractive forces** (pinch hazard). Coils need radial thickness for copper fill vs gap reluctance.

---

## 6. Simulation results (`sim/`)

Script: `sim/coax_faraday_v3.py` → `sweep_results.csv`, `voc_vs_rpm.png`, `iled_vs_rpm.png`, `voc_vs_gap.png`.

**Baseline @ 120 RPM** (P=8, gap=2 mm, 26 AWG, dual Ø20):

| Voc rms | Voc peak | f | N (approx) | R coil | I_LED est |
|---|---|---|---|---|---|
| **~4.1 V** | **~5.9 V** | 8 Hz | ~500 | ~50 Ω | **~17 mA** |

Ø3 inner same conditions: Voc rms **~0.09 V** (LED off).

Sweep covers poles {6,8,10}, gaps 1–3 mm, AWG {28,26}, RPM 60–600, both inner sizes.

FEMM not required; analytical + numpy is sufficient for desk sizing.

---

## 7. Safety

- **Pinch:** dual neo drums snap together violently — assemble with spacers, keep fingers clear, use non-ferrous tools.
- **Shatter:** NdFeB is brittle; epoxy fully in pockets; eye protection when handling.
- **Voltage:** desk-safe low V; still avoid shorted turns while cranking hard (heating + strong drag).
- **Children / pets:** choke hazard; strong magnets.
- **No mains** connection in this design.

---

## 8. What “success” means

Lit LED / measurable Voc on a multimeter while feeling Lenz drag. That is Faraday’s law — not free power.

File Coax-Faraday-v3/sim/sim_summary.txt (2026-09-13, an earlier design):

Coax Faraday v3 simulation summary
=====================================
Magnet grade assumption: N42, Br=1.3 T (N52 Br=1.44 optional)
Geometry: R_inner_face=33.0 mm, coil_radial=9.0 mm, R_outer_face≈46.0 mm

Inner magnet decision candidates:
  outer20_inner20_dual: P=8, Bg=0.311 T, Phi=6.8364e-05 Wb, FoM=P*Phi=5.4691e-04
  outer20_inner3_dual: P=12, Bg=0.311 T, Phi=1.5382e-06 Wb, FoM=P*Phi=1.8458e-05
  outer20_only_single: P=8, Bg=0.144 T, Phi=2.4958e-05 Wb, FoM=P*Phi=1.9967e-04

CHOSEN: Ø20×5 mm discs on BOTH inner and outer (dual facing).
Reason: FoM (P·Φ) dominates; Ø3 area is (3/20)^2 ≈ 2.25% → voltage collapses despite same P.
Topology: outer+inner magnet drums locked as one rotor; coil cylinder fixed stator.

Baseline @ 120 RPM (P=8, gap=2 mm, 26 AWG):
  Voc_rms ≈ 4.139 V, Voc_peak ≈ 5.853 V
  f = 8.0 Hz, N≈501, R≈49.81 Ω
  LED current est ≈ 17.04 mA (100 Ω series, 2 V LED, after naive bridge)

Ø3 inner same conditions @ 120 RPM:
  Voc_rms ≈ 0.093 V, I_led ≈ 0.0 mA

CSV: /workspace/generator-experiments/v3/sim/sweep_results.csv
Plots: voc_vs_rpm.png, iled_vs_rpm.png, voc_vs_gap.png

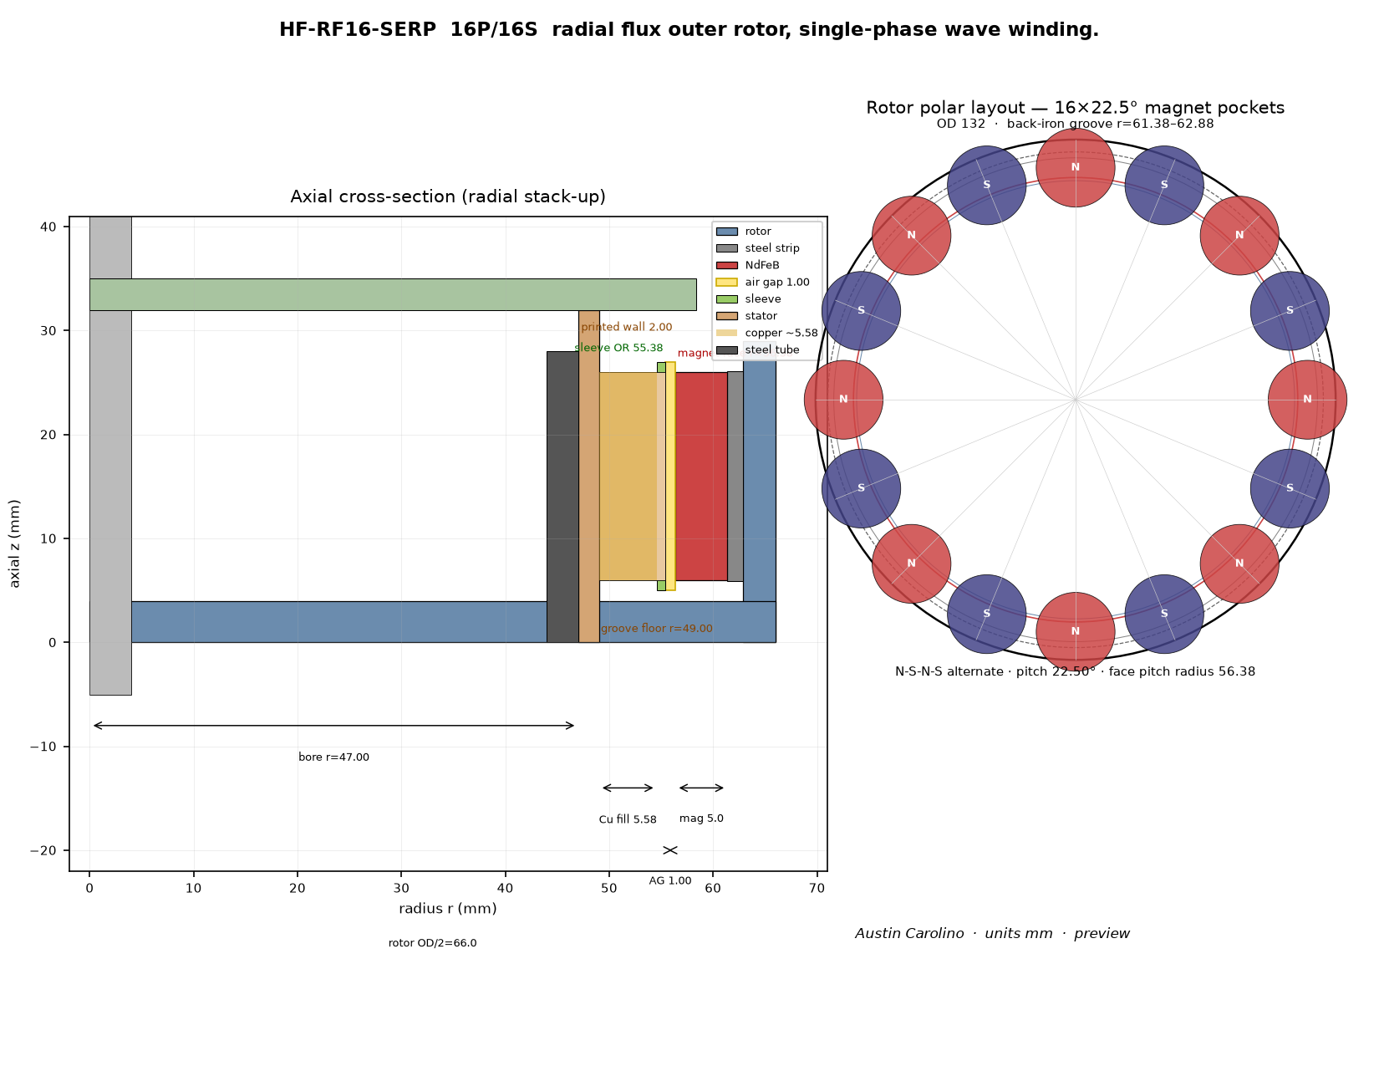
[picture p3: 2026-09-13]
HF-RF16-SERP/docs/HF-RF16-DRAWING.png

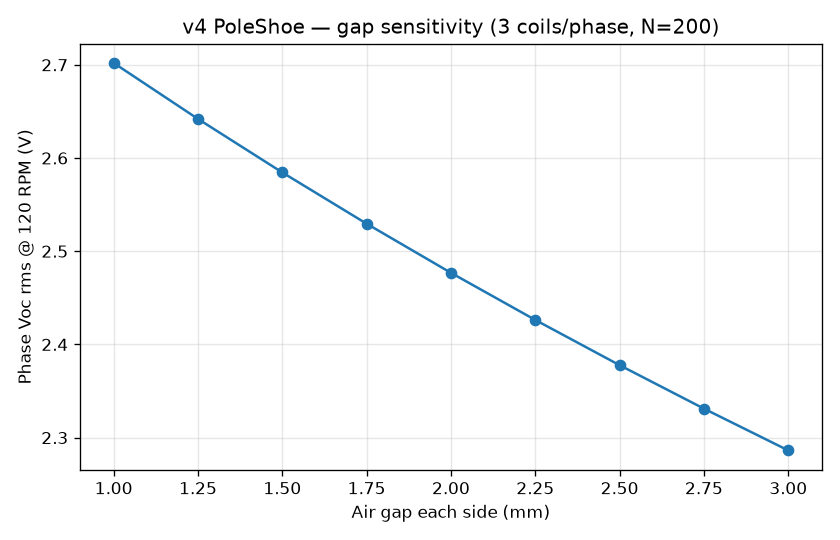
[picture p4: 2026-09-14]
AFPM-Desk-v4-PoleShoe/sim/voc_vs_gap.png

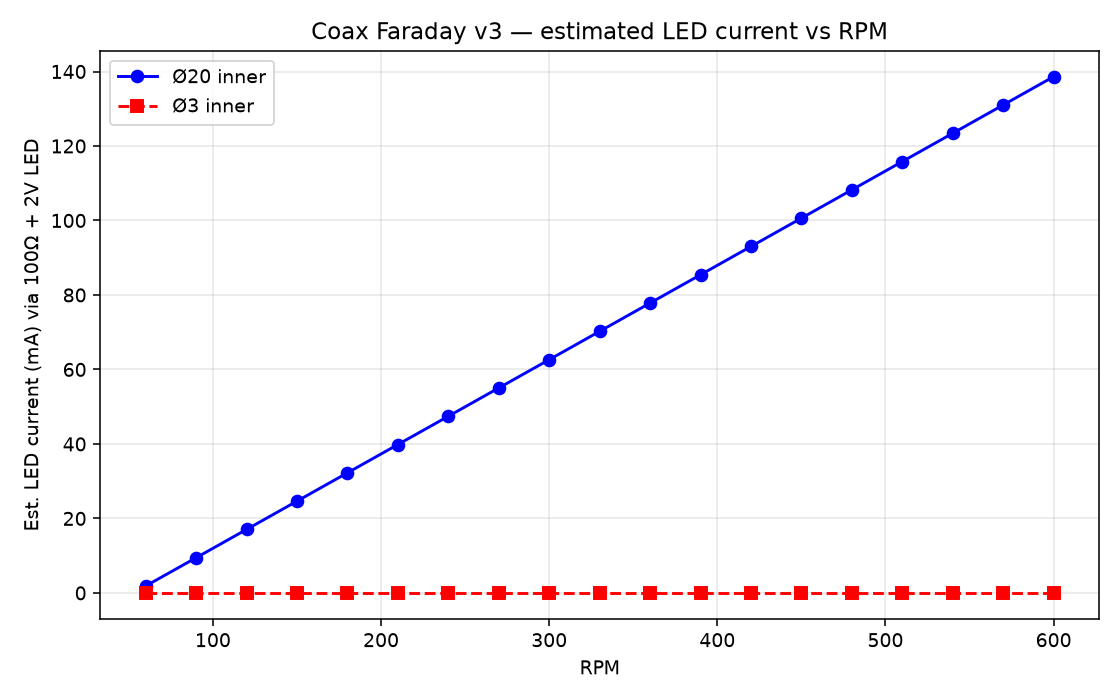
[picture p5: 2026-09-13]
Coax-Faraday-v3/sim/iled_vs_rpm.png

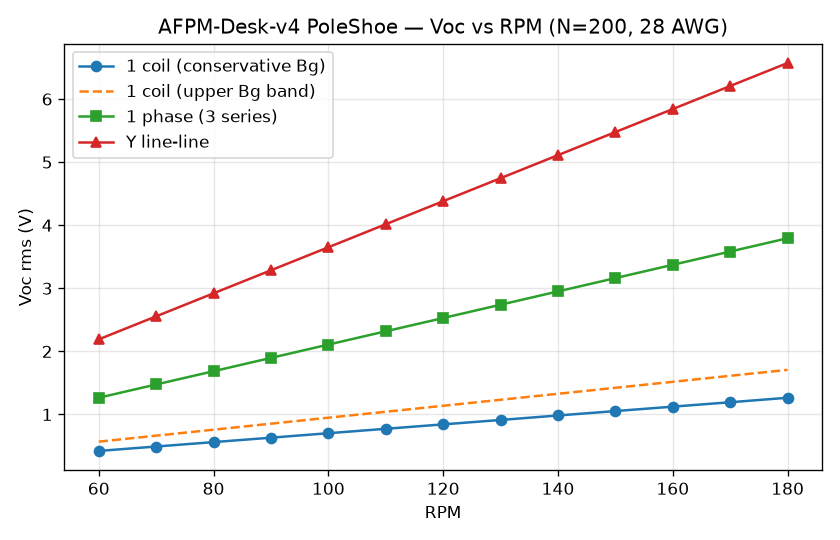
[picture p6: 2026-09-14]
AFPM-Desk-v4-PoleShoe/sim/voc_vs_rpm.png

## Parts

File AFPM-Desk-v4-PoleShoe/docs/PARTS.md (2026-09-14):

# PARTS — AFPM-Desk-v4 PoleShoe

Labeled BOM + short physics debrief per group. Orthodoxy only.

---

## Printed parts

| Label | Part | Qty | Key dims (mm) | Debrief |
|---|---|-----|---|---|
| P1 | `base_frame` | 1 | 200×180×8 base; posts Ø36×78; spacing 145 | Locates dual 608ZZ axis + stator pillars; desk-safe footprint |
| P2 | `rotor_disc_A` | 1 | Ø130×11; 12× magnet + shoe pockets; steel recess | Carries magnets/shoes/back-iron; polarity etch N/S |
| P3 | `rotor_disc_B` | 1 | same | Opposite etch so N faces S across stator |
| P4 | `stator_plate` | 1 | Ø140×12; 9 coil pockets @ PCD 90 | Coreless — copper only in gap (low cogging vs iron teeth) |
| P5 | `coil_bobbin` | 9 | core 24×16×9.2 + flanges | Defines turn length / fill; stays in stator |
| P6 | `shaft_hub` | 2 | flange Ø36; boss Ø11.8; collar | Couples Ø8 shaft ↔ rotor (M3 set + 4× M3) |
| P7 | `bearing_cap` | 2 | — | Retains 608ZZ |
| P8 | `hand_crank` | 1 | arm 90 | Mechanical input — the energy source |
| P9 | `crank_handle` | 1 | Ø14×45 | Ergonomics |
| P10 | `spacer_*` | 2+ each | Ø30×{1.0,1.5,2.0} | Sets air gap (reluctance lever) |
| P11 | `polarity_jig` | 1 | Ø126×4; 12 stations | Prevents polarity mistakes |
| P12 | `pole_shoe_holder` | 1 | optional | Teaching dry-fit of Ø18 shoes |
| P13 | `fit_coupon` | 1 | 95×55×8 | Clearance calibration |
| P14 | `electronics_tray` | 1 | 80×55×14 | Bridge + LED |

---

## Purchased hardware

| Label | Item | Qty | Spec | Notes |
|---|---|-----|---|---|
| M1 | N42 neodymium disc | **24** | **Ø20×5 mm**, axially magnetized | Austin stock; grade Br ~1.28–1.32 T |
| M2 | Mild-steel pole shoe | **24** | **Ø18×2 mm** disc / punched blank | Flux concentrator under each magnet |
| M3 | Mild-steel back-iron | **2** | **Ø118×1.5 mm**, ID ~16 mm | Return path between adjacent poles |
| B1 | Bearing | 2 | **608ZZ** / 608-2RS (Ø22×Ø8×7) | Dual support |
| S1 | Shaft | 1 | Ø8 mm × ~250 mm steel or stainless | Non-magnetic shaft optional but not required |
| W1 | Magnet wire | 1 spool | **28 AWG** enamel (26 AWG alt.) | ~200 turns/coil target |
| F1 | Fasteners | assorted | M3×8–16, M4×20–40, set screws | Prefer brass/SS near magnets |
| E1 | Epoxy | — | 5–30 min | Magnets + shoes |
| E2 | Schottky bridge + LED + resistor | 1 set | e.g. 1N5819×4, 5 mm LED, 100–220 Ω | Desk demo |
| C1 | Ø3×5 neo cans | optional | Austin stock | Not used in baseline v4 rotors; reserved for future / jig |

---

## Part-group physics notes

### Magnets (M1)
Source of **remanent flux**. Do not create energy — they set B in the magnetic circuit. Thicker than v2 (5 vs 3 mm) → higher source MMF for same gap.

### Pole shoes (M2)
Mild steel (µ_r ≫ 1) under each magnet **lowers local reluctance** and can **concentrate** flux toward the magnet face / gap. Shoes slightly undersize (Ø18 vs Ø20) keep a plastic wall and illustrate concentration geometry. They also add a bit of eddy/hysteresis loss at higher RPM — negligible at hand crank.

### Back-iron (M3)
Provides circumferential return between adjacent N/S poles on each rotor (classic AFPM). Raises useful air-gap flux vs plastic-only return (v1 lesson).

### Coils (P5 + W1)
Faraday sensors: \(\mathcal{E}=-N d\Phi/dt\). More turns → more V and more R. Nine coils enable clean 3-phase.

### Air-gap spacers (P10)
Primary experimental knob: larger gap → lower \(B_g\) → lower Voc (reluctance).

---

## Cost / sourcing ballpark

Neo discs and steel blanks dominate. Expect educational BOM on the order of tens of USD if magnets already owned (Austin has Ø20×5). Pole-shoe discs can be punched/laser-cut from 2 mm mild sheet or bought as Ø18×2 neodymium-free steel spacers.

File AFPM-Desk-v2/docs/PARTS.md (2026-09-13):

# PARTS — AFPM-Desk-v2 Labeled List + Debrief

**Build:** Dual-rotor axial-flux PM generator with steel back-iron  
**Date:** 2026-09-10 (ET)

---

## 1. Labeled printable + purchased parts

| Label | File / item | Qty | Role (physics / mechanical) |
|---|---|-----|---|
| RA | `rotor_disc_A.stl` | 1 | Holds 8 magnets; etch = N on even indices facing stator |
| RB | `rotor_disc_B.stl` | 1 | Holds 8 magnets; etch inverted so **N faces S** across gap |
| ST | `stator_plate.stl` | 1 | Coreless coil carrier; flux changes through windings |
| BF | `base_frame.stl` | 1 | Desk frame; bearing posts; stator pillars |
| H1/H2 | `shaft_hub.stl` | 2 | Couples Ø8 shaft ↔ each rotor |
| CF | `coil_former.stl` | 1 | Removable winding jig (~200 turns) |
| CB | `coil_bobbin.stl` | 6 | Optional permanent bobbins in stator pockets |
| CR | `hand_crank.stl` | 1 | Mechanical power input arm |
| CH | `crank_handle.stl` | 1 | Rotating grip |
| CAP | `bearing_cap.stl` | 2 | Retains 608 bearings |
| SP1/1.5/2 | `spacer_*.stl` | 4–8 | Sets axial air gaps / stack spacing |
| JIG | `magnet_polarity_jig.stl` | 1 | Alternating N/S placement aid (rotor-A pattern) |
| ET | `electronics_tray.stl` | 1 | Rectifier + LED / jacks bay |
| CL | `stator_clamp.stl` | 3–6 | M4 clamp washers for stator height |
| FC | `fit_coupon.stl` | 1 | **Print first** — clearance calibration |
| M1–M16 | N42 Ø20×3 mm Neo | 16 | Permanent poles (8 per rotor) |
| IRON-A/B | Mild steel disc Ø100×1.5–2 mm | 2 | **Back-iron** return path; raises \(B_g\) |
| W1–W6 | 28 AWG magnet-wire coils | 6 | EMF pickup (Faraday) |
| BRG | 608-2RS bearings | 2 | Low-friction shaft support |
| SHAFT | Steel rod Ø8 × ~220 mm | 1 | Common mechanical axis |
| RECT | Bridge rectifier 1 A+ | 1 | AC→DC for LEDs |
| LOAD | LEDs + 220–470 Ω | several | Visible sink |
| FAST | M3/M4 screws, set screws, nuts | assorted | Assembly |

---

## 2. Why each critical part (debrief)

### Magnets (N42 discs)
Provide near-constant magnetomotive force. Grade N42 balances strength vs cost/pinch hazard (N52 stronger, meaner). Disc shape packs well in printed pockets. **Alternating polarity** on each rotor is mandatory for useful \(d\Phi/dt\).

### Dual rotors (RA/RB)
Two magnet planes facing the stator double the useful axial sources compared with v1’s single plane and enable the classic SSDR flux path through the coils.

### Steel back-iron
Soft magnetic discs behind magnets lower reluctance of the return path between adjacent poles → higher gap flux for the same magnets (see PHYSICS.md). **Not** a permanent magnet; saturates if too thin under strong Neos — 1.5–2 mm mild steel is a desk compromise. Prefer non-stainless magnetic steel (e.g. 1018 / laser-cut CRS). Austenitic stainless is useless as back-iron.

### Coreless stator + coils
Copper links changing flux → EMF. No iron teeth ⇒ less cogging (hand-friendly) but larger effective magnetic gap. ~200 turns of 28 AWG: voltage-oriented educational choice.

### Air-gap spacers
Faraday EMF ∝ flux; flux falls as gap rises. Spacers make the gap a **controlled experimental variable**.

### Shaft, hubs, bearings
Define kinematic axis; hubs lock rotors in angular register so facing N/S pairs stay aligned.

### Crank
Human \(\tau\omega\) source — the only energy input that matters.

### Rectifier / LEDs
Make AC tangible as DC light; diode drop teaches why series-aiding coils matter at low V.

---

## 3. Bill of materials (approx. USD, hobby retail 2026)

| Qty | Item | Spec | Approx. $ | Notes |
|-----|---|---|---|---|
| 16 | Neo discs | N42 Ø20×3 mm Ni-plated | 15–30 | 8 reused from v1 + 8 new |
| 2 | Steel discs | Ø100 mm × 1.5–2 mm mild steel | 8–20 | Laser-cut or saw+file; ID ~14 mm hole |
| 1 spool | Magnet wire | 28 AWG enameled ≥150 m | 10–15 | |
| 2 | Bearings | 608-2RS | 3–6 | |
| 1 | Shaft | Ø8×220 mm steel | 4–10 | Longer than v1 |
| assorted | M3/M4 hardware | set screws, bolts, nuts | 5–10 | |
| 1 | Bridge rectifier | ≥1 A | 1–2 | |
| LEDs+R | 5 mm + resistors | — | 2 | |
| Filament | PLA/PETG | ~250–350 g | 6–10 | Heavier than v1 |
| Adhesive | Epoxy / CA | — | 5 | Magnets + steel |
| Safety glasses | — | — | — | **Required** |

**Total hardware excl. printer/meter:** roughly **$60–110**.

---

## 4. Key dimensions (from `parameters.scad`)

| Parameter | Value |
|---|---|
| Magnet | Ø20 × 3 mm, PCD 70 mm, 8 per rotor |
| Rotor OD | 110 mm; thickness 7 mm |
| Steel | Ø100 × 1.5 mm recess |
| Stator | OD 120 mm; thickness 10 mm; 6 coil pockets |
| Shaft | Ø8 mm |
| Bearings | 608 (8×22×7) |
| Post spacing | 120 mm |
| Base | 180 × 160 × 8 mm |
| Nominal air gap / side | 2.0 mm |

---

## 5. Safety (repeat)

1. Neo **pinch** — dual rotors **attract strongly** across the gap; keep fingers clear when bringing RA/RB near; assemble with spacers already set.  
2. Eye protection — chips.  
3. Pacemakers / cards / HDDs / phones — distance.  
4. No mains. Isolated LV educational only.  
5. Steel discs have sharp edges — deburr.  
6. Adult supervision if minors present; magnet ingestion = emergency.

---
*End PARTS — AFPM-Desk-v2*

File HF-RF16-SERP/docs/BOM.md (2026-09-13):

# BOM — HF-RF16-SERP 16P/16S

## Bought hardware

| Qty | Item | Spec / notes |
|---|---|---|
| 16 | NdFeB disc magnets | **Ø20.00 × 5.00**, axially magnetized (poles on flat faces), N-S-N-S install |
| 1 | Mild-steel strip | **1.50 × 20.00 × 386** cut length — rotor back-iron |
| 1 | Mild-steel tube | **OD ≈ 94**, wall ~**3**, length ~**28** — stator flux return (smooth, no teeth). *Legacy note “OD~47” = bore radius; use OD≈94.* |
| 2 | Ball bearings | **608ZZ** (22×8×7) |
| 1 | Shaft | **Ø8** through both bearings |
| 6 | M3 screws | Rotor coupling on **40.00** mm circle (clearance Ø3.20) |
| 4 | M3 screws + inserts | Cap → stator end bosses on **56.00** mm circle (pilots Ø2.5) |
| 6 | M2 screws or designed snaps | Sleeve halves → drum (3 per half) |
| 1 spool | Magnet wire | **26 AWG**, serpentine, target **80–120** turns |
| 4 | Diodes | Full-wave bridge |
| 1 | Capacitor | **≥1000 µF**, voltage rated above peak DC |

## Printed parts

| File | Role |
|---|---|
| `HF-RF16-ROTOR.stl` | Outer rotor cup, 16 magnet pockets, back-iron groove, 608ZZ boss |
| `HF-RF16-STATOR.stl` | Grooved drum, end-turn galleries, return slot, M3 pilots |
| `HF-RF16-SLEEVE.stl` | Two 180° shells (after winding), outer r=55.38, wall 0.80 |
| `HF-RF16-CAP.stl` | Cover, 2nd 608ZZ, grommets Ø4, 4× M3 |

## Consumables / tools

Cyanoacrylate or epoxy (optional magnet retain), feeler gauge for air gap, winding bobbin/jig, heat-set insert tip, calipers.

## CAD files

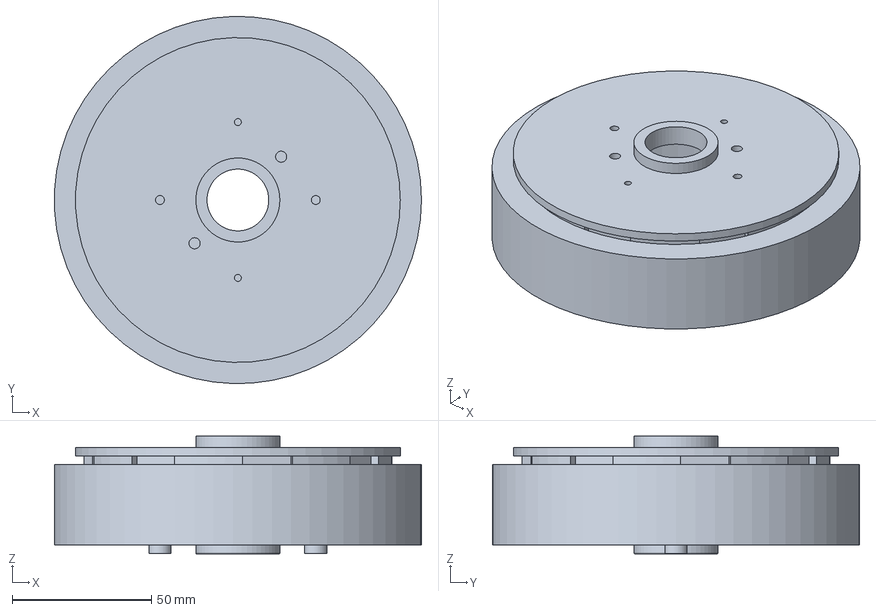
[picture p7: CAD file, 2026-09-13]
HF-RF16-SERP/step/HF-RF16-ASSEMBLY.step
131.9 x 132.0 x 42.4 mm

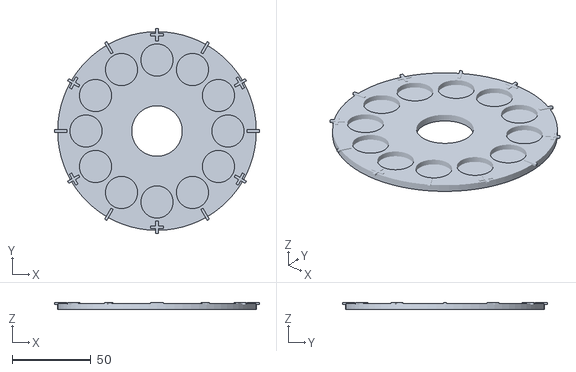
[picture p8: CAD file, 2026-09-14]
AFPM-Desk-v4-PoleShoe/stl/polarity_jig.stl
130.0 x 130.0 x 4.60

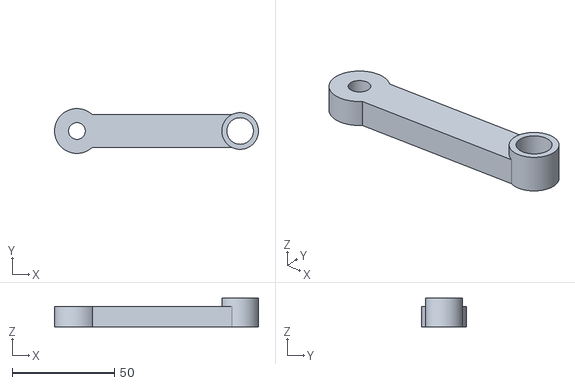
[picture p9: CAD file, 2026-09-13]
Coax-Faraday-v3/stl/hand_crank.stl
100.0 x 22.0 x 14.0

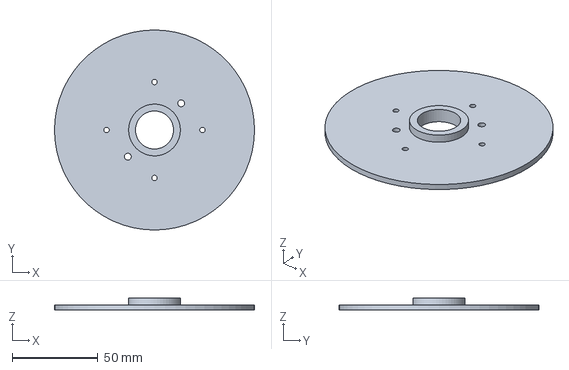
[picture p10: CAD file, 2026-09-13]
HF-RF16-SERP/step/HF-RF16-CAP.step
116.8 x 116.8 x 7.20 mm

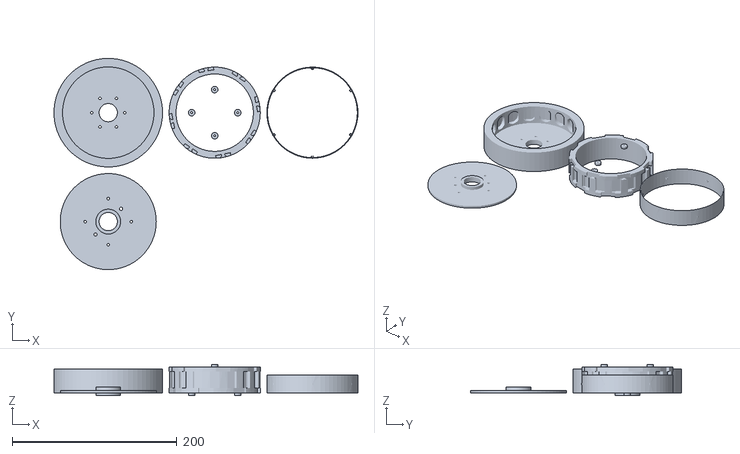
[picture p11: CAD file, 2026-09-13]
HF-RF16-SERP/stl/HF-RF16-ONEPLATE.stl
369.4 x 256.7 x 38.2

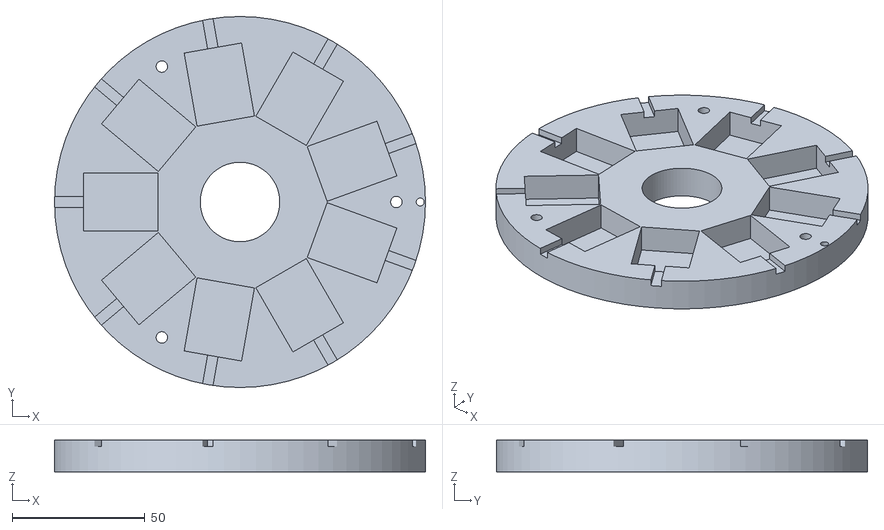
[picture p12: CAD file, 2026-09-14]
AFPM-Desk-v4-PoleShoe/stl/stator_plate.stl
140.0 x 140.0 x 12.0

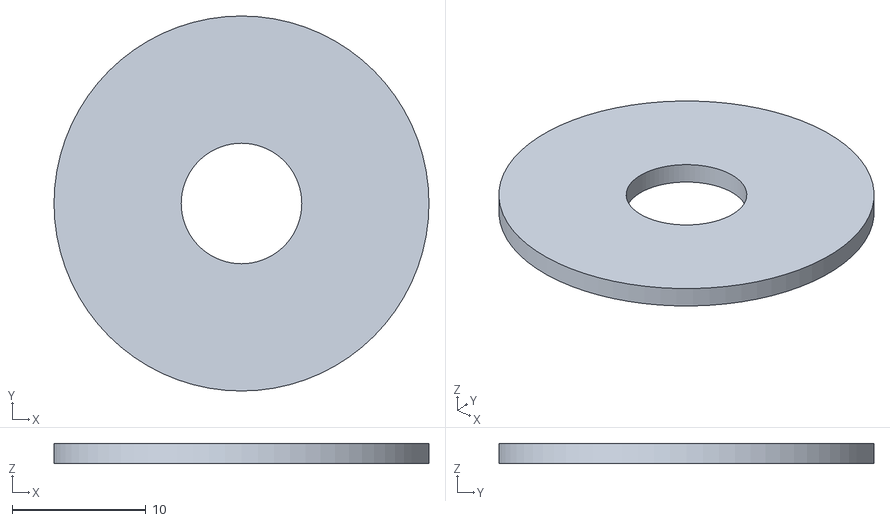
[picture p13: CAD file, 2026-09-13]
Coax-Faraday-v3/stl/spacer_1p5mm.stl
28.0 x 28.0 x 1.50

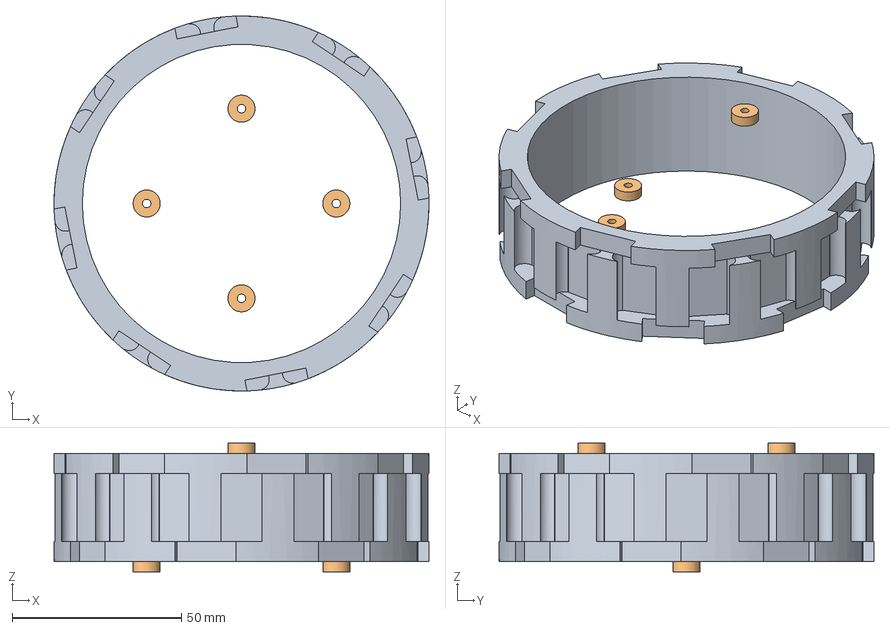
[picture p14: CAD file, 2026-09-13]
HF-RF16-SERP/step/HF-RF16-STATOR.step
110.7 x 110.7 x 38.0 mm

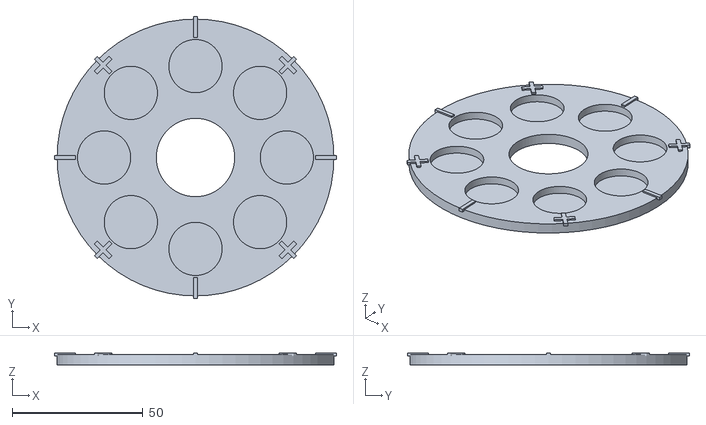
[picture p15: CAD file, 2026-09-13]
AFPM-Desk-v2/stl/magnet_polarity_jig.stl
108.0 x 108.0 x 4.60

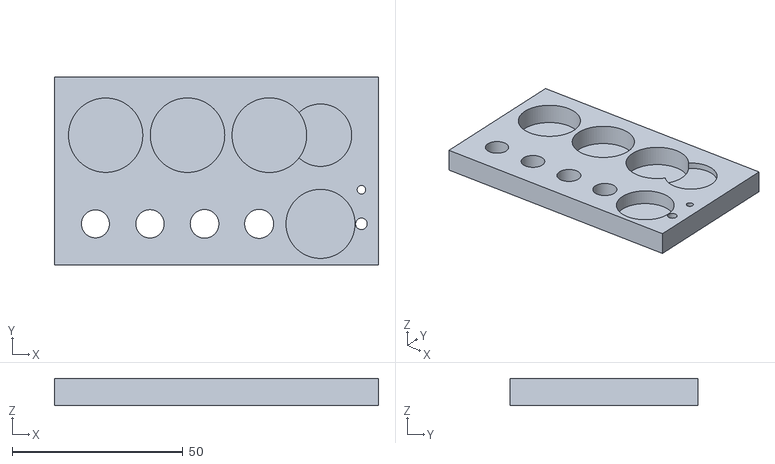
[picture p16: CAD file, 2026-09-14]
AFPM-Desk-v4-PoleShoe/stl/fit_coupon.stl
95.0 x 55.0 x 8.00

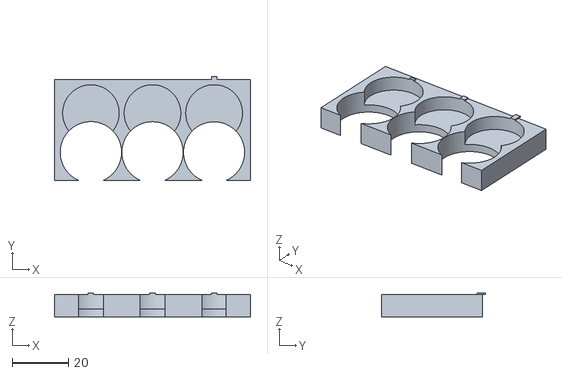
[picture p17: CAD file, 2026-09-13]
Coax-Faraday-v3/stl/fit_coupon.stl
70.0 x 37.0 x 8.40

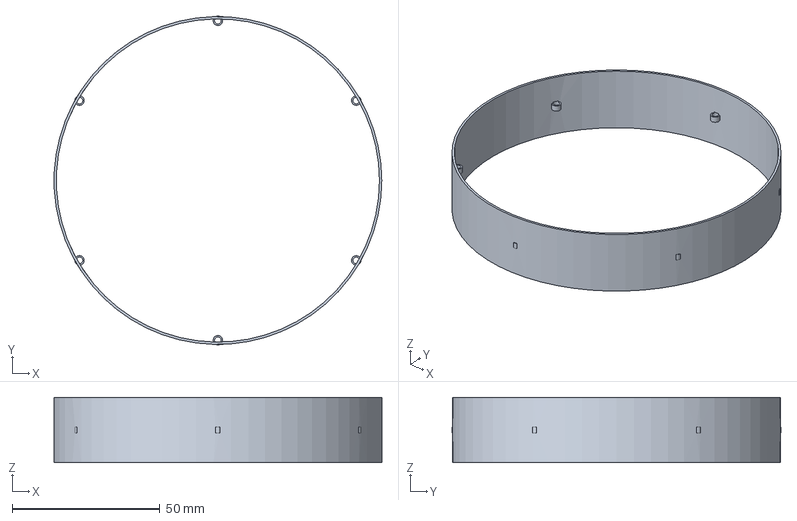
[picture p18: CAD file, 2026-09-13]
HF-RF16-SERP/step/HF-RF16-SLEEVE.step
110.7 x 111.2 x 22.0 mm

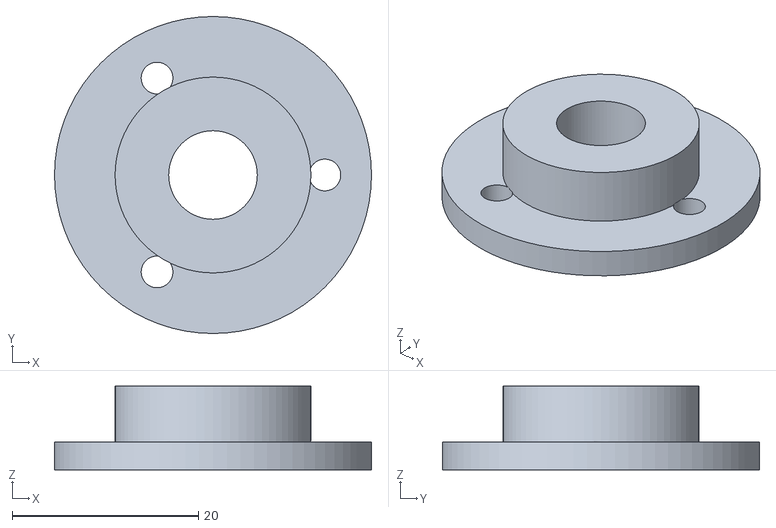
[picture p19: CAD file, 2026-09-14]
AFPM-Desk-v4-PoleShoe/stl/bearing_cap.stl
34.0 x 34.0 x 9.00

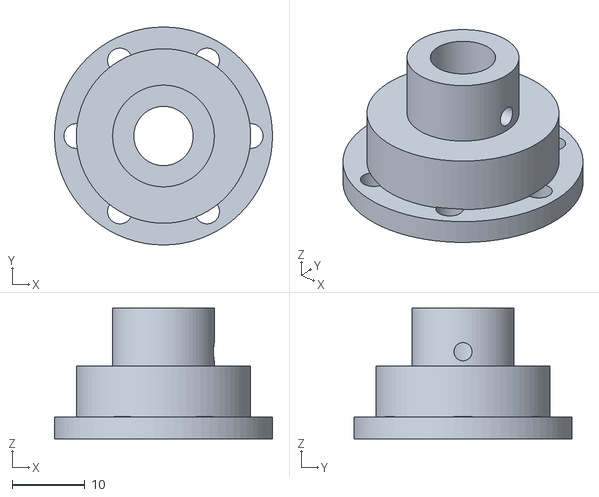
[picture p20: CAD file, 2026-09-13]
Coax-Faraday-v3/stl/shaft_hub.stl
30.0 x 30.0 x 18.0

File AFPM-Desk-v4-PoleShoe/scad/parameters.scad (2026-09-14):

// AFPM-Desk-v4 PoleShoe shared parameters (mm)
// SSDR dual-rotor axial-flux PM learning generator:
// mild-steel back-iron + mild-steel pole shoes under each magnet.
// Faraday induction education only — not free-energy / overunity.
// Target: Anycubic Kobra 3 Max, 0.4 mm nozzle, 0.2 mm layers, PETG.

$fn = 72;

// --- Printer / FDM assumptions ---
nozzle = 0.4;
layer = 0.2;
wall = 1.6;                 // load-bearing ~4 perimeters
housing_wall = 2.4;
clearance_slip = 0.35;      // shaft slip fit
clearance_loose = 0.55;
press_interference = 0.15;  // bearing pocket undersize total (coupon-test)
magnet_pocket_xy = 0.25;    // +0.25 mm on diameter
magnet_pocket_z = 0.15;     // +0.15 mm depth
elephant_foot = 0.5;

// --- Magnets (N42 Neo discs) — Austin's Ø20×5 stock ---
magnet_d = 20;
magnet_h = 5;
magnet_count = 12;          // per rotor (12+12 total)
magnet_pcd = 90;            // center pitch; ~3.3 mm edge gap between discs

// --- Mild-steel pole shoes (flux concentrators under each magnet) ---
// Slightly smaller OD than magnet teaches concentration / reluctance.
pole_shoe_d = 18;
pole_shoe_h = 2.0;          // purchased mild-steel disc or punched blank
pole_shoe_pocket_xy = 0.30;
pole_shoe_pocket_z = 0.15;

// --- Steel back-iron (purchased mild steel disc behind pole-shoe ring) ---
steel_od = 118;
steel_id = 16;              // clearance around hub boss
steel_h = 1.5;              // 1.5–2.0 mm mild steel OK
steel_recess_clearance = 0.3;

// --- Rotor printed disc ---
rotor_od = 130;
rotor_hub_bore = 12;        // seats on shaft_hub boss
rotor_thickness = 11;       // magnet + pole shoe + plastic floor + steel recess
magnet_pocket_depth = magnet_h + magnet_pocket_z;
pole_shoe_pocket_depth = pole_shoe_h + pole_shoe_pocket_z;
steel_recess_depth = steel_h + 0.2;

// --- Stator (coreless, between rotors) — 9 coils for 3-phase ---
stator_od = 140;
stator_id = 30;
stator_thickness = 12;
coil_count = 9;
coil_slot_w = 22;
coil_slot_l = 28;           // radial length of pocket
coil_slot_depth = 10;
coil_pcd = 90;
stator_pillar_pcd = 118;    // M4 pillar holes

// --- Coil bobbin (stays in stator) ---
former_core_w = 16;
former_core_l = 24;
former_flange = 2.5;
former_wind_h = 9.2;        // fits coil_slot_depth - margin

// --- Shaft / bearings ---
shaft_d = 8;
bearing_od = 22;            // 608-2RS / 608ZZ
bearing_id = 8;
bearing_h = 7;
bearing_seat_od = bearing_od - press_interference; // ~21.85; coupon-test

// --- Base / frame ---
base_w = 200;
base_d = 180;
base_h = 8;
post_h = 78;
post_spacing = 145;         // Y distance between bearing post centers (thicker stack)
post_d = 36;

// --- Axial stack targets ---
// crank | brg | hub+rotorA+steel | air | stator | air | steel+rotorB+hub | brg
air_gap_nominal = 1.75;     // mechanical per side magnet↔coil face (1.5–2.0)

// --- Crank ---
crank_arm_len = 90;
crank_arm_w = 18;
crank_arm_t = 10;
handle_d = 14;
handle_len = 45;

// --- Electronics tray ---
tray_w = 80;
tray_d = 55;
tray_h = 14;

// --- Fasteners ---
m3_clear = 3.4;
m3_tap = 2.5;
m4_clear = 4.3;

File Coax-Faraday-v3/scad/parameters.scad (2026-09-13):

// Coax Faraday Generator Experiments v3 — shared parameters (mm)
// Three-layer coaxial: outer magnets + coil stator + inner magnets
// Orthodox Faraday only — mechanical → electrical. No overunity.
// Target: Anycubic Kobra 3 Max, 0.4 mm nozzle, 0.2 mm layers, PETG preferred.

$fn = 72;

// --- Printer / FDM ---
nozzle = 0.4;
layer = 0.2;
wall = 2.0;                 // ≥2 mm walls on drums
housing_wall = 2.4;
clearance_slip = 0.35;
press_interference = 0.15;  // 608 seat undersize total (~0.1–0.2)
magnet_pocket_xy = 0.25;    // +0.25 mm on diameter (within +0.2–0.3)
magnet_pocket_z = 0.15;     // +0.15 mm depth (within +0.1–0.2)

// --- Magnets (ASSUMPTION: Ø20×5 mm N42 axial discs, not bar stock) ---
magnet_d = 20;
magnet_h = 5;
pole_count = 8;             // alternating N/S around circumference

// --- Radial stack (from axis) ---
// Inner magnet FACE at r=33; magnets 5 mm thick → pocket floor at 33-5=28
r_inner_face = 33;
air_gap = 2.0;              // each side (1–3 mm sweep; nominal 2)
coil_radial = 9.0;          // winding depth
r_coil_inner = r_inner_face + air_gap;          // 35
r_coil_outer = r_coil_inner + coil_radial;      // 44
r_outer_face = r_coil_outer + air_gap;          // 46
// Outer magnet pocket floor (further out): face + thickness
r_outer_floor = r_outer_face + magnet_h;        // 51

inner_drum_od = 2 * (r_inner_face);             // face OD before pockets nuance
inner_drum_core_r = r_inner_face - magnet_h;    // 28
outer_drum_id = 2 * r_outer_face;               // clear to faces
outer_drum_od = 2 * (r_outer_floor + wall);     // ~106

axial_magnet = 22;          // pocket axial span (~magnet_d + margin)
coil_axial = 24;
drum_axial = 28;            // outer/inner drum barrel length

// --- Shaft / bearings 608-2RS ---
shaft_d = 8;
bearing_od = 22;
bearing_id = 8;
bearing_h = 7;
bearing_seat_od = bearing_od - press_interference; // ~21.85

// --- Base ---
base_w = 160;
base_d = 140;
base_h = 8;
post_h = 70;
post_spacing = 100;         // bearing center distance along shaft axis (Y)
post_d = 36;

// --- Crank ---
crank_arm_len = 80;
crank_arm_w = 16;
crank_arm_t = 10;
handle_d = 14;
handle_len = 40;

// --- Fasteners ---
m3_clear = 3.4;
m3_tap = 2.5;
m4_clear = 4.3;

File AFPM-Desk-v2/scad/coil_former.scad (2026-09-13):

include <parameters.scad>
// Split bobbin for ~200 turns 28 AWG. Kerf allows removal after winding.

kerf = 0.4;

module coil_former() {
  difference() {
    union() {
      // bottom flange
      translate([0,0,0])
        cube([former_core_l + 2*former_flange, former_core_w + 2*former_flange, 2], center=false);
      // core
      translate([former_flange, former_flange, 2])
        cube([former_core_l, former_core_w, former_wind_h]);
      // top flange
      translate([0,0,2+former_wind_h])
        cube([former_core_l + 2*former_flange, former_core_w + 2*former_flange, 2], center=false);
    }
    // split kerf through middle (lengthwise)
    translate([(former_core_l + 2*former_flange)/2 - kerf/2, -0.1, -0.1])
      cube([kerf, former_core_w + 2*former_flange + 0.2, former_wind_h + 4.2]);
    // lead notch
    translate([-0.1, (former_core_w + 2*former_flange)/2 - 1.5, 2+former_wind_h])
      cube([3, 3, 2.2]);
  }
}

coil_former();

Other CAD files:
AFPM-Desk-v4-PoleShoe/stl/shaft_hub.stl
Coax-Faraday-v3/stl/inner_magnet_drum.stl
HF-RF16-SERP/step/HF-RF16-ROTOR.step
AFPM-Desk-v4-PoleShoe/stl/crank_handle.stl
AFPM-Desk-v2/scad/magnet_polarity_jig.scad
AFPM-Desk-v1/scad/base_plate.scad
AFPM-Desk-v1/scad/bearing_cap.scad
AFPM-Desk-v1/scad/coil_former.scad
AFPM-Desk-v1/scad/crank_handle.scad
AFPM-Desk-v1/scad/electronics_tray.scad
AFPM-Desk-v1/scad/hand_crank.scad
AFPM-Desk-v1/scad/magnet_polarity_jig.scad
AFPM-Desk-v1/scad/parameters.scad
AFPM-Desk-v1/scad/rotor_disk.scad
AFPM-Desk-v1/scad/shaft_hub.scad
AFPM-Desk-v1/scad/spacer_ring.scad
AFPM-Desk-v1/scad/stator_mount.scad
AFPM-Desk-v1/stl/base_plate.stl
AFPM-Desk-v1/stl/bearing_cap.stl
AFPM-Desk-v1/stl/coil_former.stl
AFPM-Desk-v1/stl/crank_handle.stl
AFPM-Desk-v1/stl/electronics_tray.stl
AFPM-Desk-v1/stl/hand_crank.stl
AFPM-Desk-v1/stl/magnet_polarity_jig.stl
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

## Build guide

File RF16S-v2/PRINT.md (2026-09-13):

# Anycubic print notes — RF16S-v2

Nozzle path is a slicer setting, not an STL setting. Use this:

1. Import one STL at a time (or all four if they fit).
2. Supports: Off.
3. Brim/skirt in the app: Off.
4. Wall order: outer walls first (cleaner magnet pockets).
5. Infill: gyroid 20%.
6. Slow the first 3 layers. Do not fan the first layer.
7. Let the bed cool before you peel the printed brim.

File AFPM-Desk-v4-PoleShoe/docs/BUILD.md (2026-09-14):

# BUILD — AFPM-Desk-v4 PoleShoe

## Safety first (read before touching magnets)

- **24× N42 Ø20×5** in dual arrays produce **violent snap / crush / pinch** forces. Keep fingers clear of the gap.
- Assemble rotors **one at a time**, magnets **epoxied** before bringing rotors near each other.
- Use **non-magnetic** tools (brass, plastic, wood). Keep steel screwdrivers / wrenches **away** from open magnet faces.
- Eye protection: NdFeB is brittle and can shatter.
- Children / pets: choke + pinch hazard. No mains connection in this design.

---

## 0. Fit coupon (mandatory first print)

Print `stl/fit_coupon.stl` in PETG. Measure shaft holes, 608ZZ seats, magnet Ø20×5 pocket, pole-shoe Ø18×2 pocket. Adjust `scad/parameters.scad` (`clearance_slip`, `press_interference`, `magnet_pocket_xy`, …) and re-export if needed. See `FIT_COUPON.md`.

---

## 1. Print list (PETG)

| Qty | STL | Notes |
|-----|-----|---|
| 1 | `base_frame.stl` | Flat on bed |
| 1 | `rotor_disc_A.stl` | Flat; pause for magnets optional |
| 1 | `rotor_disc_B.stl` | Flat; polarity opposite etch |
| 1 | `stator_plate.stl` | Flat |
| 9 | `coil_bobbin.stl` | Wind then insert |
| 2 | `shaft_hub.stl` | |
| 2 | `bearing_cap.stl` | |
| 1 | `hand_crank.stl` | |
| 1 | `crank_handle.stl` | |
| 2+ each | `spacer_1mm/1p5mm/2mm.stl` | Air-gap tuning |
| 1 | `polarity_jig.stl` | Magnet install aid |
| 1 | `pole_shoe_holder.stl` | Optional teaching / dry-fit |
| 1 | `fit_coupon.stl` | First |
| 1 | `electronics_tray.stl` | Optional |

Settings: **5 perimeters**, **40% infill**, **100% infill around magnet/bearing pockets**, 0.2 mm layers. Details in `PRINT_NOTES.md`.

---

## 2. Wind coils

1. Wind each bobbin **~180–220 turns of 28 AWG** (or ~150 turns 26 AWG for lower R / higher current).
2. Leave 150 mm leads; tape; lightly varnish or hot-glue ends.
3. Label coils **0…8** around the stator (phase map in `SCHEMATIC.md`).
4. Drop bobbins into stator pockets; route leads through exit channels.

---

## 3. Rotor A / B magnet + shoe install

Stack per rotor (from back → front / stator face):

```
[printed rotor] ← steel back-iron disc in back recess
               ← Ø18×2 pole shoe in each under-pocket
               ← Ø20×5 N42 in magnet pocket (face toward stator)
```

1. Place **back-iron** in rear recess; retain with 3× M3 (non-magnetic fasteners preferred) or epoxy.
2. Drop **pole shoes** into under-pockets (epoxy).
3. Using `polarity_jig.stl`, install magnets **alternating N/S** per etch:
   - **Rotor A:** even stations N toward stator.
   - **Rotor B:** polarity chosen so **N faces S** across the gap at each angular station.
4. Epoxy magnets flush; wipe squeeze-out so face is flat (air-gap critical).
5. Do **not** bring completed rotors together until shaft + spacers are ready.

---

## 4. Frame & shaft

1. Press **608ZZ** into both base posts (coupon-verified seat). Cap with `bearing_cap`.
2. Slide Ø8 shaft through both bearings.
3. Mount **hub + rotor A** on one side; **hub + rotor B** on the other; use spacer rings to set **~1.5–2.0 mm** magnet-face ↔ coil-face each side.
4. Bolt stator to three pillars with M4; verify concentric clearance to shaft.
5. Attach crank + handle; M3 set screws on hubs and crank.

---

## 5. Electrical bring-up

1. Confirm free rotation by hand **before** closing to minimum gap — feel cogging increase as gap shrinks.
2. DMM ACV on one coil while cranking ~60–120 RPM.
3. Wire 3-phase Y or Δ per `SCHEMATIC.md`; Schottky bridge → LED + series resistor on tray.
4. Expect **Lenz drag** when LED loads — that is Faraday working, not a fault.

---

## 6. Acceptance checks

- [ ] Fit coupon measurements logged
- [ ] Magnets flush; no scrape at 1.5 mm gap
- [ ] Voc scales ≈ linearly with RPM
- [ ] Scope / DMM frequency ≈ `6 × RPM/60` (P=12)
- [ ] LED lights under vigorous hand crank (wiring-dependent)

---
*End BUILD*

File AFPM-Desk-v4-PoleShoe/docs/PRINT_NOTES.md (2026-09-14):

# PRINT_NOTES — AFPM-Desk-v4 PoleShoe

**Printer:** Anycubic Kobra 3 Max  
**Nozzle:** 0.4 mm  
**Layer:** 0.2 mm  
**Material:** **PETG** (not PLA — better heat / toughness for magnet forces)

---

## Global settings

| Setting | Value |
|---|---|
| Perimeters | **5** |
| Infill | **40%** gyroid/grid |
| Around magnet / bearing / shoe pockets | **100%** solid (paint-on or modifier) |
| Top/bottom | ≥ 5 layers |
| Temps | PETG typical (hotend ~240 °C, bed ~80 °C — match your filament) |
| Cooling | moderate (PETG); avoid warping on large discs |
| Supports | generally **none** if printed as oriented below |

---

## Orientation

| Part | Orientation | Notes |
|---|---|---|
| base_frame | Base flat on bed | Elephant-foot on posts OK |
| rotor_disc_A/B | Flat (back or front) | Roundness of pockets critical — Z axis = bore axis |
| stator_plate | Flat | Coil pocket floors down or up OK |
| coil_bobbin | Flange flat | ×9 |
| shaft_hub | Flange flat | Bore vertical |
| bearing_cap | Flat | |
| hand_crank | Flat | |
| crank_handle | Standing (axis Z) | |
| spacers | Flat | |
| fit_coupon | Flat | **print first** |
| polarity_jig | Flat | |
| pole_shoe_holder | Flat | optional |

---

## Pause / insert (optional)

Advanced: pause mid-rotor to drop pole shoes then magnets, then resume — only if you trust pause accuracy. **Default:** print complete, epoxy shoes then magnets after printing (safer).

---

## Post-process

- Deburr magnet / shoe pocket edges lightly.
- Check 608ZZ press: should be firm, not crush plastic.
- PETG can string — quick heat-gun / trim on shaft bores.

---

## Skill rules applied

From `kobra-stl-from-description/SKILL.md`: walls ≥ 0.8 mm (housings 2.0–2.5); magnet pocket Ø +0.25, depth +0.15; bearing seat ~0.15 undersize total; M3 clear 3.4; elephant-foot chamfer on rotor rim.

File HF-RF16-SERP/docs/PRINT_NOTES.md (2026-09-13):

# PRINT_NOTES — HF-RF16-SERP

## Material

**PETG / ABS / ASA / nylon** — **NOT PLA** (creep, heat near magnets/bearings, poor fatigue).

## Settings (baseline)

| Setting | Value |
|---|---|
| Min wall | ≥2.00 mm |
| Perimeters | **5** |
| Infill | **40%** |
| Local solid | **100% infill within ~3 mm** of magnet pockets, grooves, bearing seats, bosses |
| Layer height | 0.20 mm (0.15 near bearing bores if possible) |
| Nozzle | 0.4 mm |

## Orientation

| Part | Orientation |
|---|---|
| Rotor | **Pockets UP** (magnet cavities open to +Z). Floor/boss on bed. Supports OK inside cup if needed for lips. |
| Stator | **Grooves UP** (open outward grooves face +Z / side per slicer — prefer drum axis vertical, grooves visible from top). |
| Sleeve halves | **Flat** on bed (OD or ID down — prefer OD down for clip accuracy). |
| Cap | **Flat** on bed (cover face down or boss up; prefer boss UP). |

## One-plate

`HF-RF16-ONEPLATE.stl` — parts spaced **8 mm**, fits a **300 mm** bed. Still print rotor alone if you want max quality on pockets.

## Post-print

- Ream 608ZZ seats to press-fit (bore printed 22.20 for 22.00 bearing).
- Stator M3 pilots are **Ø2.5** — for **heat-set M3 inserts** or tap M3×0.5.
- Rotor: 6× Ø3.20 clearance on 40 mm circle (turbine coupling).
- Deburr groove edges before winding; keep sleeve ID clear (54.58).
- Do **not** anneal PLA — you should not have used PLA.

## Fit checks before magnets

1. Sleeve halves close over wound stator to outer r≈55.38.
2. Rotor spins over sleeved stator with **~1.00 mm** radial clearance to magnet faces (feel with feeler / paper after dry-fit magnets carefully).
3. Shaft Ø8 through both 608ZZ; stator held by cap; rotor free.

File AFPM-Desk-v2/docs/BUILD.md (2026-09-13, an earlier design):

# BUILD — AFPM-Desk-v2 Assembly Instructions

Read **PARTS.md** (safety) and **FIT_COUPON.md** before full prints.

---

## 0. Print-first coupon

1. Print `stl/fit_coupon.stl` (PLA, 0.2 mm, 3 perimeters).
2. Test-fit Ø8 shaft, 608 bearing, N42 disc, M3 screw.
3. Adjust `scad/parameters.scad` (`clearance_slip`, `press_interference`, `magnet_pocket_xy`) if needed.
4. Re-export affected STLs with OpenSCAD.

---

## 1. Print all parts

See **PRINT_NOTES.md** for orientation / supports / pause layers.

**Minimum set:**
- 1× fit_coupon (done)
- 1× rotor_disc_A, 1× rotor_disc_B
- 1× stator_plate
- 1× base_frame
- 2× shaft_hub
- 1× coil_former (+ optional 6× coil_bobbin)
- 1× hand_crank, 1× crank_handle
- 2× bearing_cap
- spacers: several 1.0 / 1.5 / 2.0 mm
- 1× magnet_polarity_jig
- 1× electronics_tray
- 3–6× stator_clamp

Suggested filament: **PETG** for rotors/base (toughness); PLA OK for jigs/spacers.

---

## 2. Prepare purchased bits

1. Cut Ø8 shaft ~220 mm; deburr ends.
2. Drill/cut center hole Ø14 mm in each steel disc if not pre-cut; deburr.
3. Mark N/S on all 16 magnets with a reference magnet + permanent marker.

---

## 3. Magnet + steel install (critical)

**Rotor A (etch pattern = even N facing stator):**

1. Place disc **magnet-pocket face UP**.
2. Using jig (rotor-A pattern): epoxy magnets into pockets, alternating N/S per etch on back.
3. Cure fully (hours).
4. Flip; epoxy **steel disc into back recess**; optional M3 screws through steel into plastic (short screws — don’t pierce magnet pockets).
5. Magnets must face **away from steel** (toward stator in final stack).

**Rotor B:**

1. Same process but **invert polarity** vs A at each angular station (use B etch / opposite of jig).
2. When assembled face-to-face, each A magnet’s N should face a B magnet’s S.

**Warning:** After both rotors have magnets+steel, they **slam together** with high force. Store separated by thick wood/foam; never leave facing freely.

---

## 4. Wind coils

1. Wind **6 coils**, ~**200 turns** 28 AWG on `coil_former` (or on `coil_bobbin`).
2. Same wind direction for all; mark **start** (dot) and **finish**.
3. Leave 15 cm leads; tape; remove former (kerf).
4. Sand enamel; tin leads.
5. Measure R ≈ 3–5 Ω each; discard opens/shorts.

---

## 5. Frame + bearings

1. Press 608 bearings into base_frame posts (coupon-verified fit).
2. Install bearing_caps loosely.
3. Slide shaft through both bearings; check spin.

---

## 6. Mount rotors on shaft

Suggested axial order (crank end = −Y):

```
CRANK | BRG | H1+RA(+steel out) | air | STATOR | air | RB(+steel out)+H2 | BRG
```

1. Bolt hub H1 to rotor A (M3×12); set-screw hub to shaft near crank bearing.
2. Magnets of A face **+Y** (toward center).
3. Mount stator on three M4 pillars with clamps; leave loose for gap set.
4. Bolt hub H2 to rotor B; magnets face **−Y** (toward center).
5. Bring B toward stator **slowly with spacers** already estimating 2 mm/side — do not pinch fingers.
6. Set-screw H2; verify angular alignment: N on A opposite S on B (mark matching index).

---

## 7. Set air gaps

1. Use feeler gauge or stacked `spacer_*` rings between magnet face and coil face.
2. Target **1.5–2.5 mm each side** (start **2.0 mm**).
3. Equalize both sides so stator is centered.
4. Spin by hand: **no scrape**, mild cogging OK.
5. Tighten stator clamps / pillar nuts.

---

## 8. Wire + electronics

1. Seat coils in stator pockets (or bobbins); hot-glue lightly.
2. Route leads via wire channels to electronics_tray.
3. First wiring: see **SCHEMATIC.md** — start with one phase (2 coils series) → bridge → LED+resistor.
4. Confirm series **aiding** (voltage increases when pair connected).

---

## 9. First light / measurements

1. Multimeter **ACV** on coil pair while cranking ~60–120 RPM.
2. Compare to PHYSICS.md (~1–2 Vrms per phase ballpark @ 120 RPM).
3. Connect rectifier + LED; note crank drag increase (Lenz).
4. Log RPM, Voc, Vdc, gap.

---

## 10. Failure quick-ref

| Symptom | Fix |
|---|-----|
| Tiny V | Gap too large; wrong polarity facing; enamel not stripped |
| Rotor won’t turn | Gap too small; rotors slamming — add spacers |
| Scrape | Warped stator/rotor; re-level; increase gap |
| Phase cancel | Reverse one coil in series pair |
| Magnet exit | Re-epoxy; ensure pocket depth full |

---
*End BUILD — AFPM-Desk-v2*

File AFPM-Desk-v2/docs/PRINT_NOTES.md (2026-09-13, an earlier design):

# PRINT_NOTES — Kobra 3 Max (AFPM-Desk-v2)

**Assumptions:** 0.4 mm nozzle, 0.2 mm layers, PLA or PETG, binary STLs.  
Skill reference: kobra-stl-from-description.

---

## Global settings

| Setting | Recommendation |
|---|---|
| Layer height | 0.20 mm |
| Line width | 0.42–0.45 mm |
| Perimeters | **3–4** (rotors, base, hubs); 2–3 (spacers/jigs) |
| Infill | 25–40% gyroid/grid for rotors & base; 15% jigs |
| Top/bottom | ≥5 layers |
| Material | PETG preferred for RA/RB/BF; PLA OK elsewhere |
| Bed | Clean; brim 3–5 mm on tall posts if adhesion worries |
| Cooling | PLA normal; PETG moderate |

Bed envelope: parts fit Kobra 3 Max with ≫5 mm margin (largest ~180×160 mm base).

---

## Per-part orientation & supports

| Part | Orientation | Supports | Notes |
|---|---|---|---|
| fit_coupon | Flat as modeled | None | Print first |
| rotor_disc_A/B | **Back (steel recess) on bed** | None | Magnet pockets open upward; pause optional |
| stator_plate | Flat | None | Coil pockets up |
| base_frame | Flat base on bed | **Tree/supports under overhangs of posts if needed**; posts are vertical OK | Brim recommended |
| shaft_hub | Flange on bed | None | Bore axis vertical (roundness) |
| coil_former | Flat | None | |
| coil_bobbin | Flat | None | Print 6 |
| hand_crank | Flat | None | |
| crank_handle | Standing (axis Z) | None | |
| bearing_cap | Flat flange | None | Print 2 |
| spacer_* | Flat | None | Print extras |
| magnet_polarity_jig | Flat | None | |
| electronics_tray | Flat floor | None | |
| stator_clamp | Flat | None | Print 3–6 |

Overhangs designed ≤~45°. No long bridges >50 mm on critical faces.

---

## Pause for magnets (optional)

For **rotor_disc_A/B**:

1. Slice; note layer when magnet pocket floor is complete but before top solid layers close the pocket (pockets are open-top in this design — **pause not required** for open pockets).
2. If you modify to enclosed magnet capture lids: pause, insert magnets with correct polarity, resume.  
   **As shipped:** magnets epoxy in from the open face after printing — simpler and safer for first build.

Steel is installed **after** print into back recess — no pause needed.

---

## Clearances (designed)

| Feature | Designed fit |
|---|---|
| Shaft in hub/crank | +0.35 mm slip |
| Bearing seat | ~0.15 mm undersize on OD (coupon!) |
| Magnet pocket XY | +0.25 mm on Ø |
| Magnet pocket depth | +0.15 mm |
| M3 clearance | 3.4 mm |
| M4 clearance | 4.3 mm |

**Always validate with fit_coupon** before committing filament to base/rotors.

---

## Post-processing

- Deburr magnet pocket rims lightly so discs seat flat.  
- Check bearing seats with 608 before final press.  
- Tap M3 set-screw holes carefully or use heat-set inserts (preferred for reuse).

---
*End PRINT_NOTES*

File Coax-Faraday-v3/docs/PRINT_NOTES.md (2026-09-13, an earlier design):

# PRINT_NOTES — Kobra 3 Max (v3)

## Printer profile
- **Anycubic Kobra 3 Max**, 0.4 mm nozzle, **0.2 mm** layers  
- Material: **PETG preferred** (drums, base, hubs — toughness + temp)  
- PLA OK for fit_coupon / polarity_jig / spacers  
- Bed: PEI, dry filament; PETG bed ~70–85 °C, nozzle ~230–250 °C (tune to brand)  
- Walls: ≥4 perimeters on drums (**≥2 mm** wall param)  
- Infill: 25–40% gyroid/grid on structural; 15% OK on jig  
- Supports: generally **none** if oriented as below; tree supports only if needed under base post arches

## Orientation
| Part | On bed | Notes |
|---|---|---|
| fit_coupon | flat | as modeled |
| inner / outer drums | closed/flat end on bed | pockets face up/side; minimize support in pockets |
| stator_bobbin | flat feet down | halves already laid out |
| base | floor on bed | posts vertical |
| shaft_hub, end_cap, bearing_cap | flat face down | |
| hand_crank | arm flat on bed | |
| polarity_jig | flat | |

## Fit targets (from kobra skill)
- Magnet pocket: **Ø +0.2–0.3 mm**, depth **+0.1–0.2 mm** (params use +0.25 / +0.15)  
- 608 press: seat **~0.1–0.2 mm undersize on diameter** (`bearing_seat_od = 22 − 0.15`)  
- Always print **fit_coupon** first and adjust `parameters.scad` before committing drums

## Post-process
- Deburr pocket edges so magnets seat flat  
- Tap M3 set-screw holes or use heat-set inserts in hubs/crank  
- Light sand on stator split faces for a tight clamp

## Export
```bash
./scripts/export_stls.sh
```
OpenSCAD 2021.01+, binary STL, mm units.

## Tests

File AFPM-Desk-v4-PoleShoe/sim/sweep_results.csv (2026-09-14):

rpm | f_hz | voc_1coil_rms | voc_1coil_opt_rms | voc_phase_3series_rms | voc_line_Y_rms | bg_T | phi_Wb | N | R_coil_ohm
60 | 6.0 | 0.422 | 0.569 | 1.265 | 2.191 | 0.36 | 7.907e-05 | 200 | 3.4
70 | 7.0 | 0.492 | 0.664 | 1.476 | 2.556 | 0.36 | 7.907e-05 | 200 | 3.4
80 | 8.0 | 0.562 | 0.759 | 1.686 | 2.921 | 0.36 | 7.907e-05 | 200 | 3.4
90 | 9.0 | 0.632 | 0.854 | 1.897 | 3.286 | 0.36 | 7.907e-05 | 200 | 3.4
100 | 10.0 | 0.703 | 0.949 | 2.108 | 3.651 | 0.36 | 7.907e-05 | 200 | 3.4
110 | 11.0 | 0.773 | 1.043 | 2.319 | 4.016 | 0.36 | 7.907e-05 | 200 | 3.4
120 | 12.0 | 0.843 | 1.138 | 2.529 | 4.381 | 0.36 | 7.907e-05 | 200 | 3.4
130 | 13.0 | 0.913 | 1.233 | 2.74 | 4.746 | 0.36 | 7.907e-05 | 200 | 3.4
140 | 14.0 | 0.984 | 1.328 | 2.951 | 5.111 | 0.36 | 7.907e-05 | 200 | 3.4
150 | 15.0 | 1.054 | 1.423 | 3.162 | 5.477 | 0.36 | 7.907e-05 | 200 | 3.4
160 | 16.0 | 1.124 | 1.518 | 3.373 | 5.842 | 0.36 | 7.907e-05 | 200 | 3.4
170 | 17.0 | 1.194 | 1.613 | 3.583 | 6.207 | 0.36 | 7.907e-05 | 200 | 3.4
180 | 18.0 | 1.265 | 1.707 | 3.794 | 6.572 | 0.36 | 7.907e-05 | 200 | 3.4

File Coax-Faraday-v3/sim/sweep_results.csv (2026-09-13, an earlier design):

inner_choice | P | gap_mm | AWG | N_turns | R_coil_ohm | Bg_T | Phi_Wb | RPM | f_Hz | Voc_peak_V | Voc_rms_V | I_led_mA | FoM
inner_D20x5 | 6 | 1.0 | 28 | 838 | 109.27 | 0.3405 | 7.4875e-05 | 60 | 3.0 | 3.016 | 2.133 | 1.65 | 0.37647
inner_D20x5 | 6 | 1.0 | 28 | 838 | 109.27 | 0.3405 | 7.4875e-05 | 90 | 4.5 | 4.524 | 3.199 | 7.26 | 0.37647
inner_D20x5 | 6 | 1.0 | 28 | 838 | 109.27 | 0.3405 | 7.4875e-05 | 120 | 6.0 | 6.032 | 4.265 | 12.86 | 0.37647
inner_D20x5 | 6 | 1.0 | 28 | 838 | 109.27 | 0.3405 | 7.4875e-05 | 150 | 7.5 | 7.54 | 5.331 | 18.47 | 0.37647
inner_D20x5 | 6 | 1.0 | 28 | 838 | 109.27 | 0.3405 | 7.4875e-05 | 180 | 9.0 | 9.048 | 6.398 | 24.07 | 0.37647
inner_D20x5 | 6 | 1.0 | 28 | 838 | 109.27 | 0.3405 | 7.4875e-05 | 210 | 10.5 | 10.556 | 7.464 | 29.68 | 0.37647
inner_D20x5 | 6 | 1.0 | 28 | 838 | 109.27 | 0.3405 | 7.4875e-05 | 240 | 12.0 | 12.064 | 8.53 | 35.28 | 0.37647
inner_D20x5 | 6 | 1.0 | 28 | 838 | 109.27 | 0.3405 | 7.4875e-05 | 270 | 13.5 | 13.572 | 9.597 | 40.89 | 0.37647
inner_D20x5 | 6 | 1.0 | 28 | 838 | 109.27 | 0.3405 | 7.4875e-05 | 300 | 15.0 | 15.08 | 10.663 | 46.49 | 0.37647
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

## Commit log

2026-09-13 Add generator portfolio: HF-RF16, AFPM Desk v1–v2, Coax Faraday v3
    Organized printable Faraday generator designs with STLs, docs, and CAD.
    [HF-RF16-ASSEMBLY.step, HF-RF16-CAP.step, HF-RF16-CAP.stl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]
2026-09-13 Add RF16S-v2 dual-rotor radial flux (newer than AFPM and earlier RF16/RF88 today)
2026-09-13 RF16S-v2: add phone download links for the four printable STLs
2026-09-14 Add AFPM-Desk-v4 PoleShoe axial dual-rotor generator
    12+12 N42 with mild-steel back-iron and pole shoes, 9-coil 3-phase stator, STLs and docs.
    [base_frame.scad, base_frame.stl, bearing_cap.scad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]
2026-09-14 Point hardware repo at the idea-to-print system
2026-09-14 Document RF16S-v2 as the three-file first build; map local STL names
